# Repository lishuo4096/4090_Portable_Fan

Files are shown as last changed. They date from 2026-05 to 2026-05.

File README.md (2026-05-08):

# 4090_Portable_Fan
A high performance portable Fan based on the NIDEC AD4A31K05 which used on RTX4090.
## 视频链接：
[B站视频--功能演示及介绍](https://www.bilibili.com/video/BV1Ffurz4Ee4)
## 项目简介
这个项目是我从大二上学期就开始做的项目，在作为课设交上去之后我就再也没有动过这个项目，一年之后，我重新拾起了这个项目，将原来的方案，包括PCB，外壳，程序，装配完全推倒重做，经过几次大改版，历经两个月，总算是交出了这个完成度极高的答卷。
完成这个项目的过程，本身就是不断学习的过程，因此改版往往也意味着功能改进。到了V3版本，总算是能让我满意了。
不过，虽然使用了0805阻容，但是本项目PCB中全部使用QFN和DFN芯片，还有0.5间距FPC连接器，在焊接这块可能比较难。
复刻前，确保你有以下工具：电烙铁，热风枪，点焊机，3D打印机。
复刻交流QQ群：191731763   有问题可以在群里at我，我会耐心解答。

## 项目功能
本项目基于NIDEC AD4A31K05 三相FDB轴流风扇深度定制设计。在实用性和性能上达到了平衡。
最大输出功率10W以上，充电功率最大可达15W。睡眠平均电流不大于60uA。
使用21700电池，即使最大档位也可使用2小时以上。
项目包括PCB，程序，外壳三方面设计，全栈式开发，全部独立完成，高度可用。

## 项目参数
此处可填写项目的相关功能参数介绍，示例：

* 本项目使用STC8H1K08T作为主控芯片，实现包括触摸按键，风速，彩灯控制在内的多种功能。
* 本项目使用MP3431实现单节锂电池升压13.5V，略微超压以提高功率。
* 本项目使用SLM6610实现单节锂电池3A充电。
* 本项目使用SK6812单总线彩灯实现电量显示。

## 注意事项
* 打板时请打V3版本，前面的版本不适用附件里的外壳。如果不知道怎么导出，直接文件夹里的gerber文件即可。
* 打板需要把电池连接小板和V3主板都打，连接小板是不可缺少的。
* 外壳推荐使用PETGCF，使用PLA的话，可能因为太脆而容易导致磕碰时风扇导风网的辐条折断。
* 注意外壳公差问题，如果没有打印机的话建议多打一套备用。

## 组装流程
外壳分为5个部分。
* 风扇涵道。用于固定风扇。
* 导风网。用于约束风向，保护风扇，可旋转拆卸。
* 手柄。安装主板与电池的空间。
* 主板固定框架。用于固定主板上半部分，以及为安装涵道定位。
* 底座。防止立不住。
**详细装配可以用fusion360打开文件中的F3Z查看。**

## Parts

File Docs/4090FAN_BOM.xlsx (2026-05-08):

编号 | 数量 | 名称 | 制造商 | 封装 | 备注 | 值 | 价格 | BOM成本
1 | 1 | AD4A31K05 | NIDEC | / | 4090同款3相FDB轴流风扇 | / | ¥10.00 | ¥32.45
2 | 1 | LR2170SK 5800 | LISHEN | 21700 | 力神21700SK 5800mah | / | ¥9.98 | MB成本
3 | 1 | STC8H1K08T | STC | QFN20/L3W3/P0.4/EP | 带触摸按键控制器的8051单片机 | / | ¥1.16 | ¥6.91
4 | 1 | MP3431 | MPS | QFN13 L3W4 | 21A开关电流 BOOST升压控制器 | / | ¥2.62
5 | 1 | SLM6610 | 无锡松朗威 | DFN8 L3W3 P0.65 EP | 单节锂电池3A BUCK降压充电芯片 | / | ¥1.30
6 | 1 | SK6812SIDE-A | 欧斯科光电 | LED-SMD L4W1.6 | 单总线彩灯 | / | ¥0.15
7 | 1 | ASDM30P11TD-R | / | DFN8 L3W3 P0.65 BL | P沟道MOS管 | / | ¥0.40
8 | 1 | SS8050 | / | SOT23-3 L1.3W1.9 | NPN三极管 | / | ¥0.02
9 | 1 | TYPEC 6P W5.0 | SHOUHAN | USB-C-SMD_TYPE-C-6P-WTL5.0-108 | 5mm长度 USBC卧贴 | / | ¥0.12
10 | 1 | FXL0630-2R2 | cjiang | IND-SMD_L7.0-W6.6 | 0630 2.2uh电感 | 2.2uH | ¥0.20
11 | 1 | FXL0650-2R2 | cjiang | IND-SMD_L7.0-W6.6 | 0650 2.2uh电感，不可与0630替换 | 2.2uH | ¥0.20
12 | 2 | Resistor | / | R0805 | 1%精度 0805电阻 | 10K | ¥0.01
13 | 3 | Resistor | / | R0805 | / | 5.1K | ¥0.01
14 | 1 | Resistor | / | R0805 | / | 470R | ¥0.01
15 | 1 | Resistor | / | R0805 | / | 604K | ¥0.01
16 | 1 | Resistor | / | R0805 | / | 47K | ¥0.01
17 | 1 | Resistor | / | R0805 | / | 240R | ¥0.01
18 | 2 | Capcitor | / | C0805 | 50V耐压 C0805 MLCC | 100nF | ¥0.01
19 | 1 | Capcitor | / | C0805 | / | 4.7uF | ¥0.04
20 | 3 | Capcitor | / | C0805 | / | 22uF | ¥0.08
21 | 1 | Capcitor | / | C0805 | / | 6.8nF | ¥0.02
22 | 2 | Capcitor | / | C0805 | / | 22nF | ¥0.02
23 | 1 | Capcitor | / | C1210 | 100uF C1210 MLCC 耐压至少25V | 100uF | ¥0.24
24 | 1 | PESD0603V05P03 | / | R0603 | 5V TVS管 7.3V击穿，防静电 | 5.0V | ¥0.04
25 | 1 | 触摸天线 | 厦门芯网 | F9-10-6-9.4无针 | 触摸天线 | / | ¥0.11
26 | 1 | 3D打印外壳 | / | / | PETG-CF 89g 50元/kg | 0.2mm | ¥4.45
27 | 1 | PCB | JLC | / | 包括主板和电池连接小板 | FR4 1.6mm | ¥1.00

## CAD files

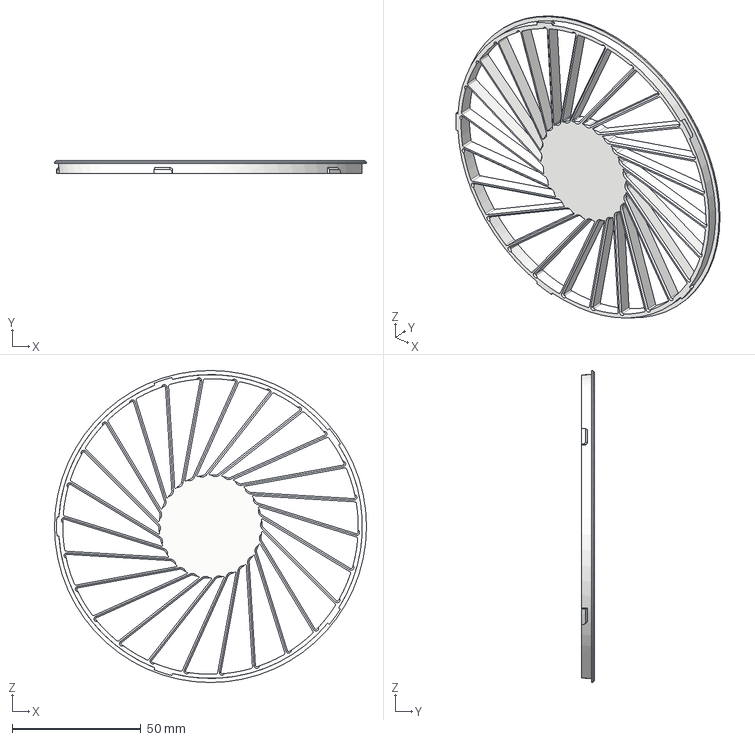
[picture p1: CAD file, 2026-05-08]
Casing/STEP/windnet.step
121.0 x 5.00 x 121.0 mm

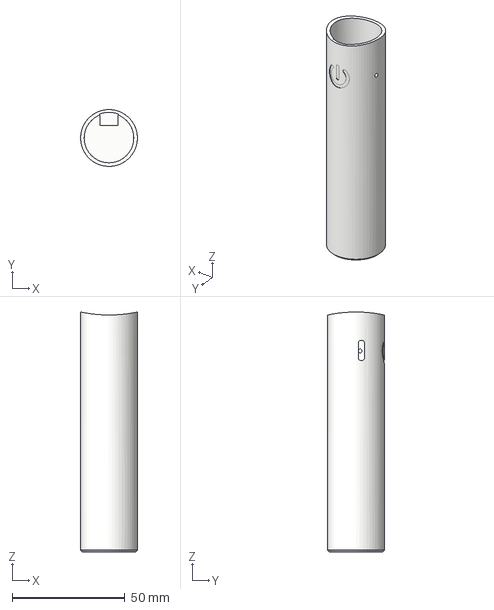
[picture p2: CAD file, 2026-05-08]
Casing/STEP/handle.step
25.2 x 25.2 x 106.5 mm

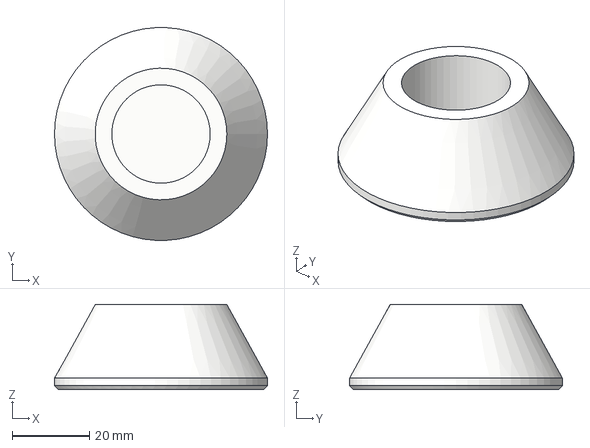
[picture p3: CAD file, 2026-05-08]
Casing/STEP/pedestal.step
55.0 x 54.9 x 22.0 mm

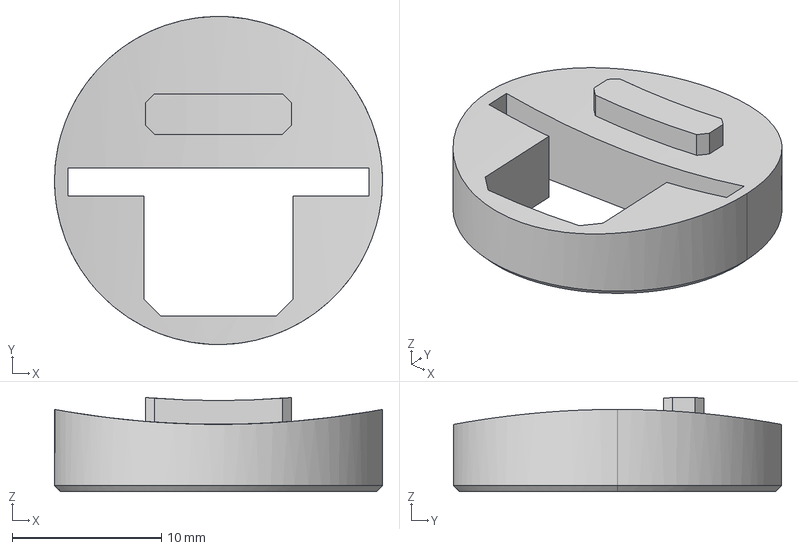
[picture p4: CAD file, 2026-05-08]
Casing/STEP/mbframe.step
22.0 x 22.0 x 6.30 mm

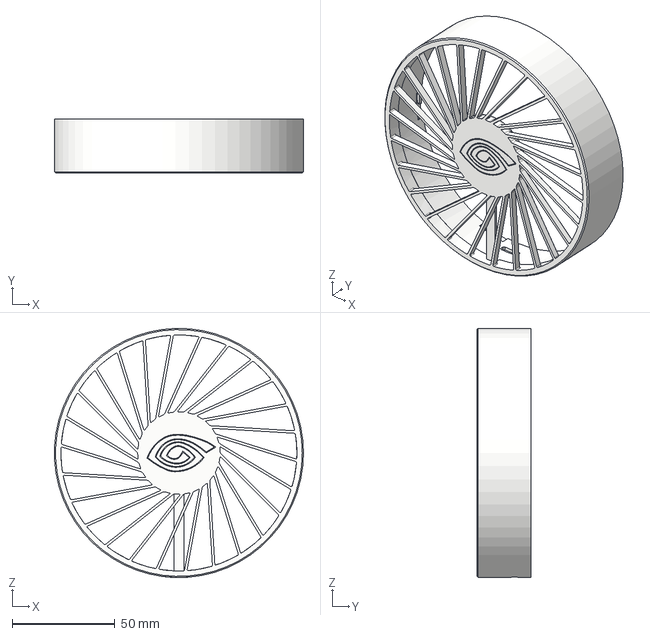
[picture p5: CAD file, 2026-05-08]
Casing/STEP/fanduct.step
120.9 x 26.4 x 121.0 mm

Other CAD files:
Firmware/keil_proj/Objects/main.obj
Firmware/keil_proj/Objects/Key.obj
Firmware/keil_proj/Objects/ADC Battery.obj
Firmware/keil_proj/Objects/TM1650.obj
Firmware/keil_proj/Objects/UART1.obj
Firmware/keil_proj/Objects/Init.obj
Firmware/keil_proj/Objects/TouchKey.obj
Firmware/keil_proj/Objects/uarttest.obj
Firmware/keil_proj/Objects/STARTUP.obj
Firmware/keil_proj/Objects/WS2812.obj
Firmware/keil_proj/Objects/test.obj
Firmware/keil_proj/Objects/Key Touchkey.obj
Firmware/keil_proj/Objects/UART.obj
Firmware/keil_proj/Objects/EERPOM.obj
Firmware/keil_proj/Objects/Gosleep.obj
Firmware/keil_proj/Objects/ISR_JMP.obj
Firmware/keil_proj/Objects/RCwakeuptest.obj

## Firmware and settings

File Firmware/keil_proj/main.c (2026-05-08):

#include "STC8H.H"
#include "main.h"

volatile bit poweron = 0;
volatile bit System_OK = 0;
volatile bit Timer0_Sync = 1;
volatile bit Timer1_Sync = 1;



void Delay_ms(uint16_t ms){//24MHZ
    //看门狗定时器无法软件关闭，因此循环时间不要超过看门狗复位时间
    uint8_t data i, j;
    while(--ms){
        _nop_();
        i = 32;
        j = 40;
        do{
            while (--j);
        } while (--i);
    }
}

void main(){
    uint8_t i = 0;//k = 10000U;
    Interupt_Init();//打开总中断和串口中断
    Timer_Init();
    RC_Wakeup_Init();//这个不需要初始化了，对于触摸按键来说，如果同时使用定时唤醒，会导致无限唤醒，无法进入睡眠
    ADC_Init();
    GPIO_Init();
    UART1_Init();
    PWMA_Init();
    TouchKey_Init();
    WS2812_Init(13);
    PWR_CTRL(PWR_ON);
    Serial_Printstrln("Initialize OK,Now Shutdown");
    Serial_Printstr("Touchkey Threshold is:");
    Serial_Printnumln(TK1_Threshold);
    while(1){
        if(!poweron){
            Enter_Sleep();
        }
        else if(!System_OK){//开机后只执行一次
            PWR_CTRL(PWR_ON);
        }
        if(Timer0_Sync){//30ms中断时序
            Timer0_Sync = 0;
            System_OK = 1;//这里变1之后上面的电源开启操作就只执行一次
            VBAT_CAL();
            Key_Sampling();
            Key_Handler();
            Adjust_Duty();
            if(++i >= 33){//1s回报一次参数
                if(Charging){
                    Serial_Printstrln("Now Charging...");
                }
                Serial_Printstr("Current Vbat:");
                Serial_Printnumln(vbat);
                Serial_Printstr("Current PWM Level:");
                Serial_Printnumln(Duty_Level);
                Serial_Printstr("Current PWM Duty:");
                Serial_Printnumln(Duty);
                Serial_Printstr("Current TouchKey Data:");
                Serial_Printnumln(TK_P11_Data);
                Serial_Printstr("Current TouchKey Baseline:");
                Serial_Printnumln(TK1_Baseline);
                i = 0;
            }
        }
        if(Timer1_Sync){//5ms中断时序
            Timer1_Sync = 0;
            WS2812_State_Machine();
            TouchKey_Handler();
        }
        WDT_CONTR |= 0X10;
    }
}
void INT0_ROUTINE(void) interrupt 0 {
    //仅用于休眠下的充电唤醒
}
void TIMER0_ROUTINE(void) interrupt 1 {//定时器0 30ms中断服务函数
    Timer0_Sync = 1;
    If_Back_Sleep();//为定时关机提供时序
}
void TIMER1_ROUTINE(void) interrupt 3 {//定时器5ms中断服务函数
    Timer1_Sync = 1;
}
void Touchkey_ISR(void) interrupt 13{
    //TSSTA2 |= 0X80;
    //这个中断函数仅用于给一个入口，防止程序跑飞
    //B7 TSIF为中断标志，且能唤醒CPU
}
            /*Serial_SendByte('<');
            Serial_Printnum(i);
            Serial_SendByte('>');
            Serial_Printstr("{plotter}");
            Serial_Printnum(TK_P11_Data);
            Serial_SendByte(',');
            Serial_Printnum(TK1_Baseline);
            Serial_SendByte(',');
            Serial_Printint16ln(TK_P11_Pressed * 10000U);*/

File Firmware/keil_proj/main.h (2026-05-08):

#ifndef __MAIN_H__
#define __MAIN_H__
#include "STC8H.H"

#define Main_FOSC 24000000UL//24MHZ
#define Baud_Rate 1000000UL
#define UART_Timer_Reload_Value (65536UL - (Main_FOSC / (4UL * Baud_Rate)))
#define SAVE_SET_ADDR 0x0000;//高级定时器触发值
#define PWM_Period 1000U//高级定时器周期值

void Delay_ms(uint16_t ms);

void GPIO_Init();
void Interupt_Init();
void ADC_Init(void);
void PWMA_Init();
void PWMA_Config();
void Timer_Init(void);
void UART1_Init(void);
void TouchKey_Init();
void RC_Wakeup_Init();

extern volatile bit UART_Buffer_Overflow;
extern volatile bit poweron;
extern volatile bit System_OK;
extern volatile bit Timer0_Sync;
extern volatile bit Timer1_Sync;
extern volatile uint16_t vbat;
extern volatile bit was_enter_sleep;//
extern volatile bit need_wakeup_sampling;//被外部中断唤醒，需要进行一次采样

#define MP3431_EN_PIN P10
#define FAN_PWR_ON (P3PU |= 0X10)//打开上拉
#define FAN_PWR_OFF (P3PU &= ~0X10)//关闭上拉
#define TK_PIN P11
#define WS2812_SPI_PIN P13
#define WS2812_PWR_ON do {P16 = 1; P17 = 1;} while(0)
#define WS2812_PWR_OFF do {P16 = 0; P17 = 0;} while(0)
#define PWM_PIN P33
#define RXD_PIN P30
#define TXD_PIN P31
#define Charging (!P32)//P32为低电平
#define Touchkey_Normal_Set do {IE2 &= ~0X80; TSCTRL &= ~0X80; TSCTRL = 0X25; TSCTRL |= 0X80;} while(0)//正常工作时TSCTRL寄存器为0xA5，睡眠状态为0x0D
#define Touchkey_Sleep_Set do {IE2 |= 0X80; TSSTA2 = 0X80; TSCTRL &= ~0X80; TSCTRL = 0X0D;} while(0)//都需要先将B7位清零，才能写入

void VBAT_CAL(void);

#define Brt_Rise 0U
#define Brt_Keep_High 1U
#define Brt_Fall 2U
#define Brt_Keep_Low 3U
extern volatile uint8_t Breath_State;//呼吸模式
extern volatile uint16_t Breath_Counter;//呼吸计数器，实现呼吸计数
void WS2812_State_Machine();
void WS2812_Init(unsigned char Pin_Sel);
void WS2812_Send_Data(unsigned char WS2812_Num,unsigned char Red,unsigned char Green,unsigned char Blue);

extern volatile uint16_t TK1_Baseline;
#define Total_TK_Num 1U
uint16_t TouchKey_Read();
extern volatile bit TK_P11_Pressed;
extern volatile uint16_t TK_P11_Data;
extern volatile uint16_t TK1_Threshold;
extern uint16_t Touchkey_Threshold_CAL(uint16_t Data);
void TK_Write_Th(uint16_t Th);
extern uint8_t WKUP_Handler();
void TouchKey_Handler();

extern volatile uint8_t BAT_Status;
#define BAT_FULL     0  // ≥4000 mV
#define BAT_HIGH     1  // ≥3800 mV
#define BAT_MEDIUM   2  // ≥3600 mV
#define BAT_LOW      3  // ≥3400 mV
#define BAT_CRITICAL 4  // ≥3000 mV
#define BAT_DRAINED  5  // <3000 mV
#define BAT_DEAD     6  // <2750 mv

void Serial_Printstr(uint8_t *str);
void Serial_Printstrln(uint8_t *str);
void Serial_SendByte(uint8_t dat);
void Serial_Printnumln_with_Word(uint8_t *str,uint16_t num);
void Serial_Printnum(uint16_t num);
void Serial_Printnumln(uint16_t num);
void Serial_Printint16ln(int16_t num);

extern volatile uint16_t Duty;
extern volatile bit Fine_Tune_Inc;   // 正在微调增加占空比
extern volatile bit Fine_Tune_Dec;   // 正在微调减小占空比
extern volatile uint8_t Duty_Level;//当前风速

extern volatile const uint16_t Duty_Table[11];
void Key_Sampling(void);
void Key_Handler(void);
void Adjust_Duty(void);
#define Duty_Reg PWMA_CCR4

#define Save_Addr 0x100
#define Save_VBAT_Addr 0x0100
#define Save_Dutylevel_Addr 0x102
void Save_Set_To_EEPROM(uint16_t addr,uint16_t Set1,uint16_t Set2);
uint16_t Read_Set_From_EEPROM(uint16_t addr);

#define PWR_ON 1
#define PWR_OFF 0
void PWR_CTRL(bit CTRL);

void If_Back_Sleep(void);
void Enter_Sleep(void);
extern volatile bit Back_Sleep;

#define MDU_CMD_NOP           0   // 无动作，待机
#define MDU_CMD_MUL32         2   // 32位乘法 (耗时3时钟)
#define MDU_CMD_DIVU32        4   // 无符号32位除法 (耗时19时钟)
#define MDU_CMD_DIVS32        6   // 有符号32位除法 (耗时21时钟)
#define MDU_CMD_NORM          8   // 数据规格化 (Normalization)
#define MDU_CMD_LOGIC_SHIFT   10  // 逻辑左移/右移 (Logical Shift)
#define MDU_CMD_ARITH_SHIFT   11  // 算术右移 (Arithmetic Shift)
#define MDU_CMD_ADD32         12  // 32位加法
#define MDU_CMD_SUB32         14  // 32位减法

#endif

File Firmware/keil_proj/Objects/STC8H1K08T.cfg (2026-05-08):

[STC]
Version=V6.95Z
McuType=STC8H1K08T
Option=BFAFF7FFFFFFFFFFFFFFFFFFFFFFFDFD54
Frequency=24.000
AutoReload=1
RepeatInterval=4
SoundTip=3
AutoSelectPort=15
U8WVcc=0
U8WOnLinePower=1
U8WAdcMin=5
U8WAdcMax=15
MaxBaud=500000
ListenModify=1

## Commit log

2026-05-08 First time commit
    [4090FAN_BOM.xlsx, ADC Battery.obj, EERPOM.obj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]
2026-05-08 Expand README with project details and instructions
    Added project introduction, features, parameters, and assembly instructions.
2026-05-08 Clean up README by removing assembly images
    Removed several images and descriptions related to assembly steps.
